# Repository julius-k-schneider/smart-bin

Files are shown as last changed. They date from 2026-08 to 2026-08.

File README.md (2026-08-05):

# AI-Powered Smart Waste Sorting Bin - Sortio

A prototype of a waste bin that sorts for you, plus the city dashboard that keeps an eye on a whole fleet of them.

- **The bin** (`pi/`, `printables/`) is a 3D printed housing with a Raspberry Pi. It detects someone stepping up, photographs what they are holding, has an AI classify it as Paper or Plastic and opens the matching flap with a servo. Ultrasonic sensors in the lids measure how full it is.
- **The dashboard** (`src/`, `scripts/`) is a React + Vite frontend on a FastAPI + SQLite backend. It shows fill levels of all bins across Cologne on a map, raises alerts and plans collection routes. Real bins report over a WebSocket; the remaining locations are simulated so the demo works without hardware.

## Repository layout

| Path | What it is | Documentation |
|---|---|---|
| `pi/` | Firmware for the bin - classification, flaps, fill-level reporting | [`pi/readme.md`](pi/readme.md) - wiring, GPIO pins, calibration, setup |
| `printables/` | STL files for the housing, gears and sensor mounts | [`printables/readme.md`](printables/readme.md) - part list and print settings |
| `scripts/` | Backend: REST API, WebSockets, SQLite, route generation | this file |
| `src/` | Dashboard frontend | this file |

## Compartment naming

The bin and the dashboard use different words for the same thing, because the dashboard models a standard three-compartment city bin while the prototype sorts two categories:

| Bin (`pi/smartbin.py`) | Dashboard / API | Meaning |
|---|---|---|
| Paper | `recycling` | Paper flap and the sensor in that lid |
| Plastic | `trash` | Plastic flap and the sensor in that lid |
| - | `compost` | Exists in the dashboard only, no hardware for it |

## Architecture

Three components that talk over two WebSockets and one REST API:

```mermaid
flowchart LR
    subgraph Bin["Smart bin (Raspberry Pi)"]
        S["HC-SR04 sensors<br/>trigger + 2× fill level"]
        C["Camera"]
        V["Servos / flaps"]
        P["pi/smartbin.py"]
        S --> P
        C --> P
        P --> V
    end

    AI["AI API<br/>(KIConnect NRW)"]
    P -- "photo (HTTPS)" --> AI
    AI -- "Paper / Plastic" --> P

    subgraph Server["Backend (scripts/)"]
        B["backend.py<br/>FastAPI"]
        D[("SQLite<br/>data/smart-bins.db")]
        R["route_service.py"]
        B <--> D
        B --> R
    end

    P -- "fill levels, 1 Hz<br/>ws://…/ws/ingest" --> B

    subgraph UI["Dashboard (src/)"]
        F["React + Vite"]
    end

    B -- "city snapshots<br/>ws://…/ws" --> F
    F -- "REST /api/*" --> B
```

The Pi does two independent jobs: classifying waste with the camera and the AI
API, and reporting how full its bins are. Only the second one talks to the
dashboard. Bins without hardware are simulated by the backend.

## Features

**Smart bin:**

- Proximity trigger with an ultrasonic sensor, then an automatic photo
- Waste classification through a vision AI model (KIConnect NRW), reduced to Paper, Plastic or "no waste detected"
- Servo-driven flap that only opens for the matching category
- OLED status display on the bin
- Two ultrasonic fill-level sensors, reported to the dashboard once per second
- Every peripheral is optional - a missing display, camera, servo or backend does not stop the rest

**Dashboard:**

- Responsive navigation with Overview, Smart Bins, Route Planning, Smart Analytics and Settings pages
- Persistent bin data and measurements in SQLite
- REST API for adding, deleting and inspecting bins
- Live city-wide WebSocket snapshot stream, pushed on every data change and at least every 30 seconds
- Device ingest WebSocket for real Raspberry Pi bins reporting their fill level once per second
- Cologne map using OpenStreetMap tiles through Leaflet
- 20 simulated smart bin locations around Cologne
- Threshold filter for collection planning
- Summary cards for total bins, full bins, almost-full bins, average fill, and connection status
- Sortable smart bin table and individual detail views
- Backend route generation with a nearest-neighbor heuristic
- Multi-part Google Maps export for generated collection routes
- Custom collection route start points
- Reusable map, address search and manual coordinate location picker
- Demo settings for pausing updates and resetting all fill levels
- Straight-line Haversine distance estimate for the MVP route
- Smart Analytics page with sustainability KPIs - note that this page shows hard-coded example figures, it is not calculated from the measurements

## Environment

Create `.env.local` in the project root when you want to override the default city WebSocket URL:

```env
VITE_SMART_BIN_CITY_URL=ws://localhost:8181/ws
VITE_SMART_BIN_API_URL=/api
```

If the file is missing, the frontend defaults to `ws://localhost:8181/ws` and `/api`.

## Run The Demo

Install frontend and backend dependencies:

```bash
npm install
pip install -r requirements.txt
```

Start the backend and simulator:

```bash
npm run server
```

The server provides REST endpoints and a WebSocket on port `8181`. Optional CLI arguments are:

```bash
npm run server -- 8181 cologne-smart-bin-mock
```

(`npm run mock-server` is an alias for the same command. It is the real backend either way - the "mock" only refers to the simulated bins it serves when no hardware is connected.)

Start the frontend in another terminal:

```bash
npm run dev
```

Open the Vite URL shown in the terminal, usually `http://localhost:5173`.

## Simulated Data

`scripts/backend.py` sends a city-wide frame whenever the data changes and, through the simulation loop, at least every 30 seconds. Every frame contains:

- `city: "Cologne"`
- `device_group_id`
- `timestamp_ms`
- `bins`

Note that a connected Raspberry Pi reports once per second, and every accepted device frame triggers a snapshot broadcast - so with real hardware attached the dashboard receives roughly one frame per second rather than one every 30 seconds.

The mock server simulates 20 stable locations around Cologne, including Koelner Dom, Koeln Hauptbahnhof, University of Cologne, Rheinauhafen, Neumarkt, Heumarkt, Stadtgarten, Deutz, Ehrenfeld, Nippes, Muelheim, Poller Wiesen, and Rheinpark.

Fill levels change only slightly during each update. Bin data, current fill levels and measurement history are stored in `data/smart-bins.db`.

## Real Hardware

### Bill of materials

Everything needed for one physical bin. The GPIO pins for each part are in [`pi/readme.md`](pi/readme.md).

| Qty | Part | Notes |
|---|---|---|
| 1 | Raspberry Pi with Raspberry Pi OS (Bookworm or newer) | needs `picamera2` / `rpicam-still` for the CSI camera path |
| 3 | HC-SR04 ultrasonic sensor | 1× trigger at the front, 2× fill level in the bin lids |
| 3 | Voltage divider, e.g. 1 kΩ + 2 kΩ resistor | **required** - the HC-SR04 ECHO pin outputs 5 V, the Pi GPIO is 3.3 V only |
| 1 | SG92R micro servo | Paper flap |
| 1 | SG90 micro servo | Plastic flap |
| 1 | SBC-OLED01 128×64 I2C display (address 0x3C) | optional - the program runs without it |
| 1 | Camera | either a CSI camera on the Pi, or a phone running the "IP Webcam" app (see `CAMERA_URL`) |
| 1 | 5 V power supply for the servos | driving both servos from the Pi's 5 V rail can brown it out |
| - | Jumper wires, screws | |
| - | 3D printed housing and mounts | STL files and print settings in [`printables/readme.md`](printables/readme.md) |

An account for the KIConnect NRW AI API is needed for the waste classification (`KICONNECT_API_KEY`, see [`pi/env.example`](pi/env.example)). Fill-level reporting works without it.

### Reporting protocol

A Raspberry Pi bin (`pi/smartbin.py`) reports its measured fill levels to the backend through a second WebSocket, `ws://<host>:8181/ws/ingest`. Each frame names the bin and one or more compartments:

```json
{
  "bin_id": "CGN-001",
  "timestamp_ms": 1737045000000,
  "compartments": {
    "recycling": { "fill_level_percent": 41.9, "distance_cm": 34.9 },
    "trash": { "fill_level_percent": 88.4, "distance_cm": 12.6 }
  }
}
```

The backend validates the frame, writes it to the database and broadcasts the updated city snapshot to every dashboard right away. Compartments that are not part of the frame keep their value. As long as a device is connected, its bin is excluded from the simulation, so real and simulated bins can run side by side. Device history is thinned to one entry per 30 seconds instead of one per frame.

The exclusion works per bin, not per compartment. The Pi has fill-level sensors for two compartments only (`recycling` and `trash`), so the `compost` value of a live bin keeps whatever it had before the device connected and no longer moves - the dashboard currently shows it like any other value. Keep that in mind when reading a live bin's compost level or its overall status.

Set `SMART_BIN_INGEST_TOKEN` on the backend to require the same token as a `?token=` query parameter on the ingest socket. If the variable is unset, the socket is open, which is fine for a local demo.

Wiring, GPIO pins, calibration and the Pi setup are documented in [`pi/readme.md`](pi/readme.md).

Address search uses the public OpenStreetMap Nominatim service only when a search is submitted. Search requests are limited to one per second and biased towards Cologne.

## Threshold And Routes

The dashboard defaults to an 80% collection threshold. Move the “Include bins from fill level” slider to include bins where at least one compartment is greater than or equal to the selected value.

Click “Generate collection route” to build a route from the fixed Waste Collection Depot. The current route optimizer:

- starts at the depot
- visits the nearest unvisited included bin
- continues until every included bin is visited
- returns to the depot
- estimates total distance with the Haversine formula

This is an MVP approximation with straight-line distances. It does not call a paid API and does not need API keys. The route service can later be replaced with OSRM, OpenRouteService, Google Maps, or another routing engine.

## Notes

- Python 3.10 or newer is required for the backend.
- The Raspberry Pi reports real fill levels; all other bins stay simulated.
- Dashboard user authentication is intentionally out of scope for this prototype.

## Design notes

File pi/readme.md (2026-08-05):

# Smart Bin - Raspberry Pi

`smartbin.py` runs on the bin itself. It does two independent jobs:

1. **Sorting** - when something comes close to the trigger sensor it takes a
   photo, has the AI classify it as Paper or Plastic and opens the matching
   flap with a servo.
2. **Fill-level reporting** - two more ultrasonic sensors sit in the lids and
   look down into the bins. Once per second their measurement is pushed to the
   dashboard backend over a WebSocket, where it replaces the simulated values.

Both run at the same time; the fill-level reporting lives in a background
thread and never blocks the sorting.

The dashboard those reports go to, the backend and the full bill of materials
are described in the [main README](../README.md). The printed parts are in
[`../printables/readme.md`](../printables/readme.md).

## Wiring

All sensors are HC-SR04 (5 V VCC, GND, TRIG, ECHO). **ECHO puts out 5 V and
must go through a voltage divider** (e.g. 1 kΩ / 2 kΩ) before it touches a Pi
GPIO, which is 3.3 V only.

| Function | Component | TRIG / Signal | ECHO |
|---|---|---|---|
| Trigger (object in front of the bin) | HC-SR04 | GPIO23 (Pin 16) | GPIO24 (Pin 18) |
| Fill level Paper -> section `recycling` | HC-SR04 | GPIO5 (Pin 29) | GPIO6 (Pin 31) |
| Fill level Plastic -> section `trash` | HC-SR04 | GPIO20 (Pin 38) | GPIO21 (Pin 40) |
| Flap Paper | SG92R servo | GPIO18 (Pin 12) | - |
| Flap Plastic | SG90 servo | GPIO17 (Pin 11) | - |
| Display | SBC-OLED01 (I2C, 0x3C) | SDA GPIO2 (Pin 3) | SCL GPIO3 (Pin 5) |

The pins are the `FILL_SENSORS` / `SERVO_PINS` constants at the top of
`smartbin.py`.

## Fill-level calibration

The distance from the sensor is converted into a percentage with two
constants in `smartbin.py`:

```python
BIN_EMPTY_CM = 55.0  # sensor -> bin floor, counts as 0 %
BIN_FULL_CM  = 7.0   # sensor -> waste surface when full, counts as 100 %
```

Measure both values once on the real bin and put them in. Each report is the
median of three pings, so a single bad echo does not show up in the dashboard.

## Setup

```bash
pip install -r requirements.txt

cp env.example ~/.kiconnect.env
chmod 600 ~/.kiconnect.env   # contains the API key
nano ~/.kiconnect.env        # fill in API key, camera and dashboard settings
```

The dashboard settings are:

| Variable | Meaning |
|---|---|
| `SMART_BIN_WS_URL` | Ingest socket of the backend, e.g. `ws://192.168.0.10:8181/ws/ingest` |
| `SMART_BIN_ID` | Which bin this Pi reports as - has to exist in the dashboard already |
| `SMART_BIN_INGEST_TOKEN` | Shared secret, must match the backend's `SMART_BIN_INGEST_TOKEN` |

Run it manually:

```bash
source ~/.kiconnect.env && python3 -u smartbin.py
```

Or as a service:

```bash
sudo cp smartbin.service /etc/systemd/system/
sudo systemctl enable --now smartbin
journalctl -u smartbin -f
```

## Behaviour when something is missing

Every peripheral is optional and the program keeps running without it: no OLED,
no camera, no servos, no `websocket-client`, no reachable dashboard. The
dashboard connection reconnects on its own with a backoff of 2 s up to 30 s, so
the Pi survives a backend restart without intervention.

This also covers failures at runtime, not just at startup: if a photo fails -
network camera unreachable, phone gone from the WLAN, CSI camera or
`rpicam-still` broken - the display shows `Camera error`, that trigger is
skipped and the program carries on. Fill-level reporting runs in its own thread
and is unaffected by camera or AI problems.

What each missing part costs you:

| Missing | Consequence |
|---|---|
| OLED | No display output, everything else works |
| Camera or AI key | No classification, no flap opens - fill levels still reported |
| Servos | Classification still runs and is shown, no flap moves |
| `websocket-client` or dashboard | No fill levels in the dashboard, sorting works |
| Fill-level sensor without echo | That compartment is skipped in the report, the other one is still sent |

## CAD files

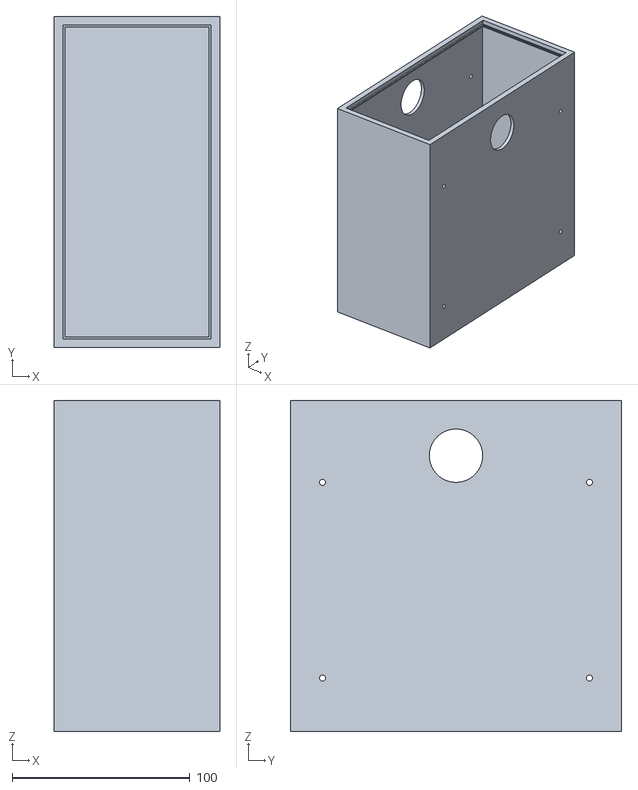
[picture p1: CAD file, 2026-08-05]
printables/middle.stl
93.0 x 186.0 x 186.0

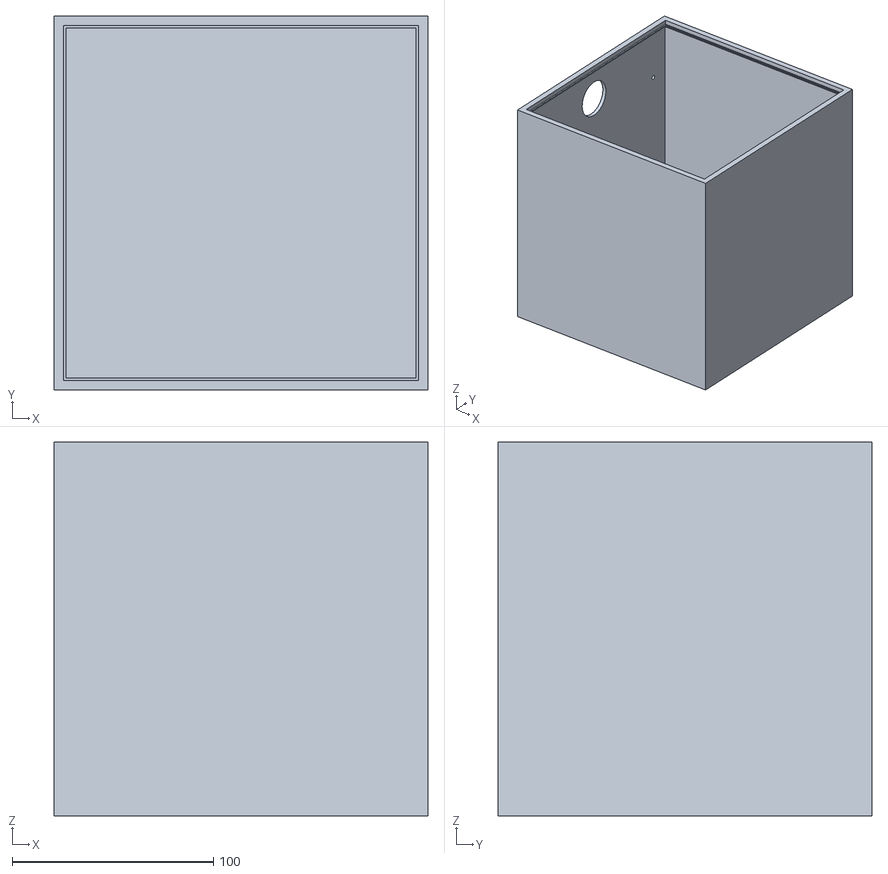
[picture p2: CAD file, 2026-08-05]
printables/bin.stl
186.0 x 186.0 x 186.0

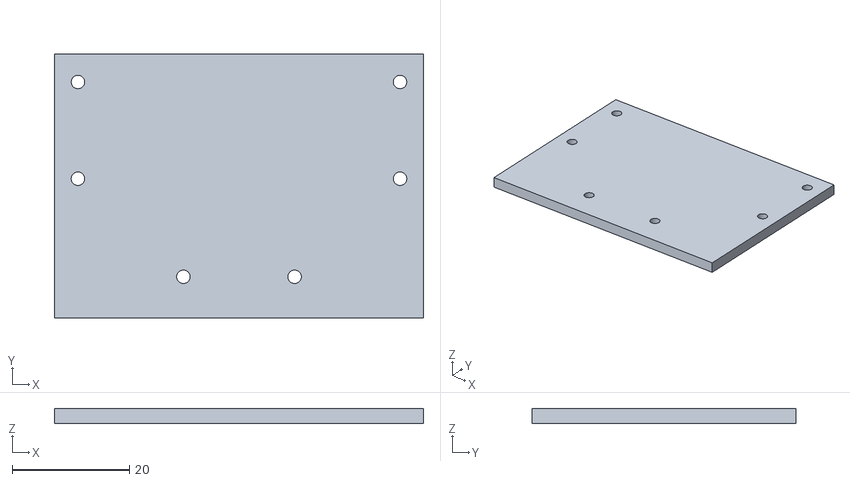
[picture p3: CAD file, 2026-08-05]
printables/holding_plate.stl
63.0 x 45.0 x 2.50

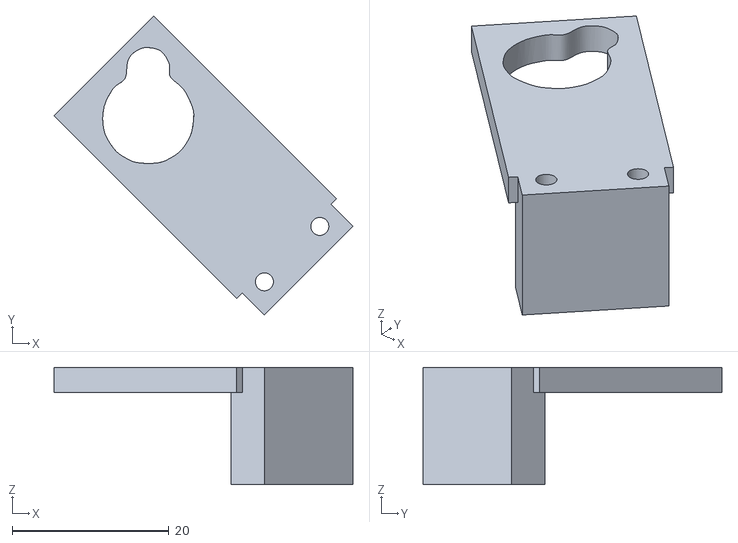
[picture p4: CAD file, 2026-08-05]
printables/servo_holder.stl
38.2 x 38.2 x 15.0

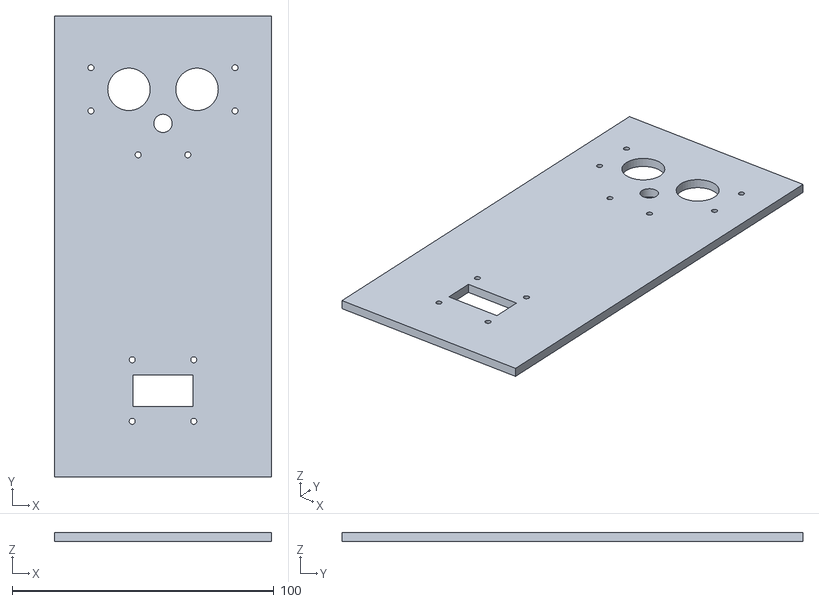
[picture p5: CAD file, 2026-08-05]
printables/lid_middle.stl
83.0 x 176.0 x 3.50

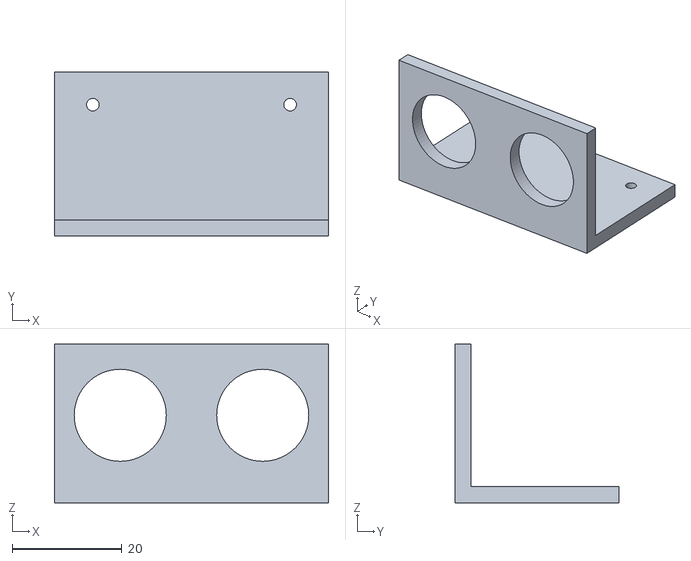
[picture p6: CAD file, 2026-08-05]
printables/distance_sensor_holder.stl
50.0 x 30.0 x 29.0

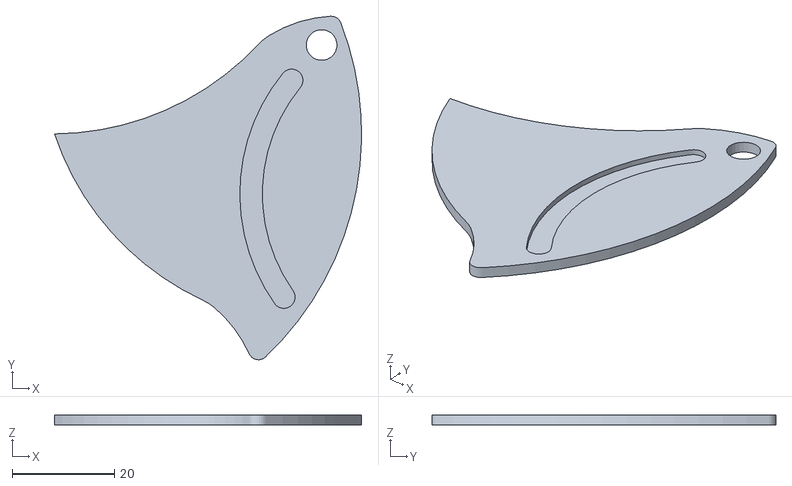
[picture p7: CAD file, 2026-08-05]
printables/door_blade.stl
60.0 x 67.1 x 2.00

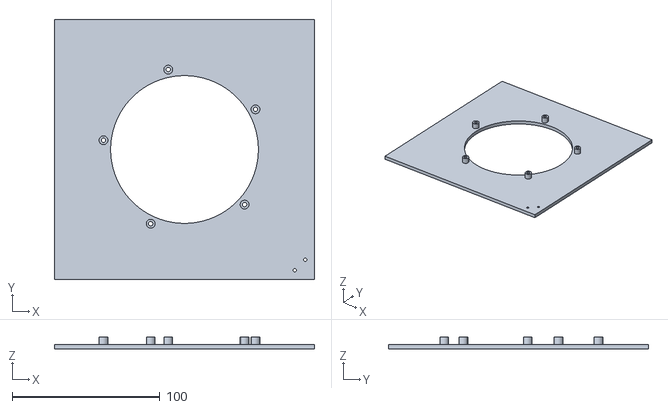
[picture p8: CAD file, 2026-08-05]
printables/lid_bin.stl
176.0 x 176.0 x 8.20

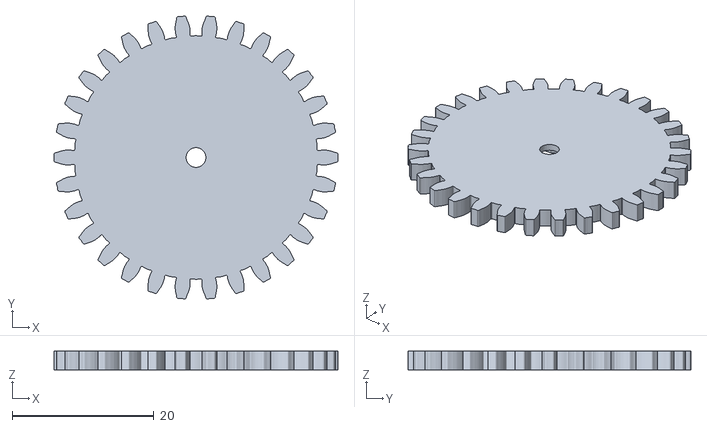
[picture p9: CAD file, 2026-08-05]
printables/pinion.stl
40.1 x 39.9 x 2.64

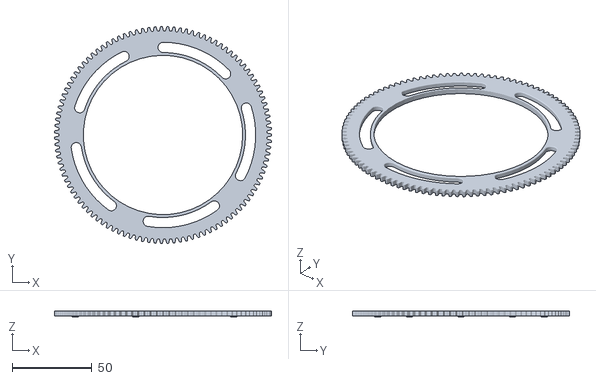
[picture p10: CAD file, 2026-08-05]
printables/ring_gear.stl
136.2 x 136.2 x 3.80

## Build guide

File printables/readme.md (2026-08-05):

# Smart Bin - 3D printed parts

All STL files for the bin housing, the sorting mechanism and the sensor/servo
mounts. Dimensions below are the actual bounding boxes of the STL files, so you
can check them against your printer before slicing.

## Part list

| File | Size (X × Y × Z, mm) | Qty | What it is |
|---|---|---|---|
| `bin.stl` | 186 × 186 × 186 | 2 | The waste container itself - one per category (Paper, Plastic) |
| `middle.stl` | 93 × 186 × 186 | 1 | Middle section between the two bins |
| `lid_bin.stl` | 176 × 176 × 8.2 | 2 | Lid for `bin.stl`, holds the fill-level sensor looking down |
| `lid_middle.stl` | 83 × 176 × 3.5 | 1 | Lid for the middle section |
| `door_blade.stl` | 60 × 67.1 × 2 | 2 | Flap that opens the way into one bin, driven by a servo |
| `ring_gear.stl` | 136.2 × 136.2 × 3.8 | 1 | Ring gear of the flap drive |
| `pinion.stl` | 40.1 × 39.9 × 2.6 | 1 | Pinion on the servo horn, drives the ring gear |
| `servo_holder.stl` | 38.2 × 38.2 × 15 | 2 | Mount for the SG90 / SG92R servos |
| `distance_sensor_holder.stl` | 50 × 30 × 29 | 3 | Mount for an HC-SR04 |
| `holding_plate.stl` | 63 × 45 × 2.5 | 1 | Mounting plate for the electronics |

The quantities follow the wiring in [`../pi/readme.md`](../pi/readme.md): two
servos and two flaps (one per category), three HC-SR04 (one trigger sensor at
the front, one in each bin lid). Print a single bin and one lid if you only
want to test one category.

## Build volume

`bin.stl` and `middle.stl` are **186 mm tall**, so you need a printer with at
least ~190 mm in Z (an Ender 3 or Prusa MK-series is fine, a Prusa Mini at
180 mm is not). Everything else fits on any common bed.

## Suggested print settings

These are starting values, not measured project settings - adjust them to your
printer and filament.

| | Structural parts (`bin`, `middle`, lids, `holding_plate`) | Gears (`ring_gear`, `pinion`) | Mounts (`servo_holder`, `distance_sensor_holder`, `door_blade`) |
|---|---|---|---|
| Material | PLA or PETG | PETG (less wear) | PLA or PETG |
| Layer height | 0.2 mm | 0.15 mm | 0.2 mm |
| Infill | 15 % | 30-40 % | 25 % |
| Perimeters | 3 | 4 | 3 |
| Supports | only for overhangs in the lids | no | no |

Notes:

- Print the gears with a **finer layer height** - tooth flanks that are too
  coarse make the flap drive jam.
- `door_blade.stl` is only 2 mm thick and slides. Print it flat, and if it is
  tight in the ring gear, sand the edge instead of scaling the part.
- If the servo does not sit tight in `servo_holder.stl`, your printer is likely
  printing slightly small - check the horizontal expansion / XY compensation
  setting rather than editing the STL.

Wiring, GPIO pins and calibration are documented in
[`../pi/readme.md`](../pi/readme.md), the electronics you need to buy are listed
in the [main README](../README.md).

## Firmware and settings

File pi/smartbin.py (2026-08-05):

#!/usr/bin/env python3
"""Smart-Bin: on proximity (< THRESHOLD_CM) takes a photo, sends it to the AI
API (KIConnect NRW) for waste classification and shows the result on the OLED.
It then opens the matching bin flap (Paper / Plastic) with a servo.

Two more distance sensors sit inside the bins and measure how full they are;
that value is pushed to the dashboard backend over a WebSocket every second.

- Trigger sensor: HC-SR04 on GPIO23 (TRIG) / GPIO24 (ECHO, via resistor).
  Raw measurement with RPi.GPIO + internal pull-down (robust, with timeouts).
- Fill-level sensors: one HC-SR04 per bin, mounted in the lid looking down.
  Paper on GPIO5/GPIO6, Plastic on GPIO20/GPIO21 (see FILL_SENSORS).
- Camera: network camera (phone app "IP Webcam") via CAMERA_URL; falls back to
  the local CSI camera (picamera2) or rpicam-still if CAMERA_URL is unset.
- Display: SBC-OLED01 128x64 on I2C-1 (SDA Pin3 / SCL Pin5), address 0x3C.
- AI: photo -> OpenAI-compatible /chat/completions -> category + reason.
  Credentials come from environment variables (see env.example):
    KICONNECT_BASE_URL, KICONNECT_API_KEY, KICONNECT_MODEL, CAMERA_URL
- Dashboard: SMART_BIN_WS_URL, SMART_BIN_ID, SMART_BIN_INGEST_TOKEN.
- Images are stored with a timestamp in ~/captures/.
"""
import base64
import json
import os
import re
import subprocess
import threading
import urllib.request
import urllib.error
from datetime import datetime
from pathlib import Path
from time import sleep, time

import RPi.GPIO as GPIO

# --- Configuration ---
TRIG = 23
ECHO = 24
# Fill-level sensors: one HC-SR04 per bin, mounted in the lid looking straight
# down at the waste. Keyed by the dashboard section they report to.
# GPIO5/6 and GPIO20/21 are free here - the trigger sensor uses 23/24, the
# servos 17/18 (hardware PWM pins stay clear) and the OLED sits on I2C (2/3).
FILL_SENSORS = {
    "recycling": {"flap": "Paper", "trig": 5, "echo": 6},
    "trash": {"flap": "Plastic", "trig": 20, "echo": 21},
}
BIN_EMPTY_CM = 55.0    # sensor -> bin floor, counts as 0 % full
BIN_FULL_CM = 7.0      # sensor -> waste surface, counts as 100 % full
FILL_SAMPLES = 3       # median over N pings - kills ultrasonic outliers
FILL_PING_GAP_S = 0.06 # HC-SR04 needs a short pause between pings
REPORT_INTERVAL_S = 1.0  # how often the fill levels go to the dashboard

# Dashboard backend (scripts/backend.py). SMART_BIN_ID must match a bin that
# already exists in the dashboard, otherwise the backend rejects the frames.
DASHBOARD_URL = os.environ.get("SMART_BIN_WS_URL", "ws://192.168.0.10:8181/ws/ingest")
BIN_ID = os.environ.get("SMART_BIN_ID", "CGN-001")
INGEST_TOKEN = os.environ.get("SMART_BIN_INGEST_TOKEN", "")
RECONNECT_MAX_S = 30.0
THRESHOLD_CM = 15.0    # trigger when distance is below this
PRE_PHOTO_S = 0.5      # wait after trigger before the photo (avoids motion blur)
NUM_PHOTOS = 1         # number of photos per trigger
COOLDOWN_S = 3.0       # lock-out after a trigger
MEAS_TIMEOUT_S = 0.03  # max wait per echo edge
RESULT_S = 5.0         # how long the result stays on the display
SAVE_DIR = Path.home() / "captures"

# Camera: picamera2 keeps the camera open (fast, <1 s/photo). Keep resolution
# moderate - enough for classification and small to upload. rpicam-still stays
# a fallback if picamera2 is missing.
CAMERA_SIZE = (1280, 960)
CAMERA_WARMUP_S = 1.5  # once at startup, for exposure/white balance

# Network camera (e.g. phone app "IP Webcam"): if CAMERA_URL is set, the photo
# is fetched via HTTP from there instead of the CSI camera.
# Example: CAMERA_URL="http://192.168.178.99:8080/shot.jpg"
CAMERA_URL = os.environ.get("CAMERA_URL", "")

# Servos (SG92R + SG90): one servo per bin/category.
# Motion: CLOSED (0 deg) -> OPEN (180 deg), hold SERVO_OPEN_S, then CLOSED again.
SERVO_PINS = {"Paper": 18, "Plastic": 17}
SERVO_FREQ = 50        # Hz - standard for hobby servos (20 ms period)
SERVO_CLOSED = 0.0     # closed end position (deg) - one edge
SERVO_OPEN = 180.0     # open end position (deg) - the opposite edge
SERVO_MOVE_S = 0.6     # time for the servo to reach the end position
SERVO_OPEN_S = 5.0     # how long the flap stays open

# AI API (from environment; defaults as fallback)
AI_URL = os.environ.get("KICONNECT_BASE_URL", "https://chat.kiconnect.nrw/api/v1")
AI_KEY = os.environ.get("KICONNECT_API_KEY", "")
AI_MODEL = os.environ.get("KICONNECT_MODEL") or "Mistral Small 3-2-24b Instruct KI:Inferenz.nrw"

CATEGORIES = ("Paper", "Plastic")  # only these open a bin
SYSTEM_PROMPT = (
    "You are a waste classifier for a smart bin. "
    "You get a photo. If it clearly shows a single waste item, classify it as "
    "EXACTLY one of: Paper, Plastic. "
    "If NO waste is visible - for example only a hand, an empty scene, or an "
    "unrelated object - use the category None. "
    "Reply ONLY with a JSON object in exactly this format, no other text, no Markdown: "
    '{"category": "<Paper|Plastic|None>", "reason": "<max 8 words, in English>"}. '
    "Choose exactly one category. Do not express uncertainty."
)

SAVE_DIR.mkdir(exist_ok=True)

# --- GPIO setup (internal pull-down keeps ECHO cleanly LOW at rest) ---
GPIO.setmode(GPIO.BCM)
GPIO.setwarnings(False)
GPIO.setup(TRIG, GPIO.OUT)
GPIO.setup(ECHO, GPIO.IN, pull_up_down=GPIO.PUD_DOWN)
GPIO.output(TRIG, False)
for _sensor in FILL_SENSORS.values():
    GPIO.setup(_sensor["trig"], GPIO.OUT)
    GPIO.setup(_sensor["echo"], GPIO.IN, pull_up_down=GPIO.PUD_DOWN)
    GPIO.output(_sensor["trig"], False)
sleep(0.3)

# The three HC-SR04 run from two threads - without this lock they would ping
# into each other's echo window and report garbage.
_ping_lock = threading.Lock()
_stop = threading.Event()

# --- WebSocket client for the dashboard (optional, fails cleanly) ---
try:
    import websocket  # pip install websocket-client
except ImportError as e:
    websocket = None
    print(f"websocket-client missing ({e}) - no fill levels sent to the dashboard.")

# --- Servos (optional, fail cleanly) ---
_servos = {}  # category -> GPIO.PWM
try:
    _closed_duty = 2.5 + (SERVO_CLOSED / 180.0) * 10.0  # duty for the closed position
    for _cat, _pin in SERVO_PINS.items():
        GPIO.setup(_pin, GPIO.OUT)
        _pwm = GPIO.PWM(_pin, SERVO_FREQ)
        _pwm.start(_closed_duty)  # move to closed position at startup
        _servos[_cat] = _pwm
    sleep(SERVO_MOVE_S)       # time for both to reach the closed position
    for _pwm in _servos.values():
        _pwm.ChangeDutyCycle(0)  # pulse off -> servo quiet/power saving
    print(f"Servos ready: {[(k, SERVO_PINS[k]) for k in _servos]}")
except Exception as e:
    _servos = {}
    print(f"Servos unavailable ({e!r}) - continuing without servos.")
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

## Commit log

2026-08-05 Add 3D models
    [bin.stl, distance_sensor_holder.stl, door_blade.stl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]
2026-08-05 Report real fill levels from the Pi to the dashboard
    Add two HC-SR04 fill-level sensors to the bin and stream their readings to
    the dashboard backend over a WebSocket once per second.
    Pi (pi/smartbin.py):
    - Paper sensor on GPIO5/6, Plastic on GPIO20/21; 23/24, 17/18 and I2C stay free
    - Distance to percent via BIN_EMPTY_CM/BIN_FULL_CM, median of three pings
    - Background thread keeps the socket open and reconnects with 2s..30s backoff
    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
2026-08-05 Keep the bin running when the camera fails
    A failing photo took the whole program down: photo() had no error handling
    and the main loop only catches KeyboardInterrupt. An unreachable network
    camera (URLError), a broken CSI camera (RuntimeError) or a missing
    rpicam-still (CalledProcessError) therefore also killed the fill-level
    reporting, which has nothing to do with the camera.
    capture_and_classify() now catches the failure, shows "Camera error" on the
    OLED and skips that trigger. The background reporting thread is unaffected.
    This is what pi/readme.md already promised ("no camera ... keeps running"),
    so the section now spells out that runtime failures are covered too and adds
    a table of w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
    [smartbin.py]
2026-08-05 Document the hardware, the parts to print and the real broadcast rate
    printables/readme.md was empty. It now lists every STL with its actual
    bounding box (parsed from the files), the quantity needed per bin, a build
    volume warning - bin.stl and middle.stl are 186 mm tall - and suggested
    print settings.
    README.md gains an architecture diagram and a bill of materials, including
    the voltage divider the HC-SR04 ECHO lines need.
    Two corrections to existing text:
    - The city snapshot is not sent "every 30 seconds". Every accepted device
    frame triggers a broadcast, so a connected Pi produces about one per
    second.
    - Excluding a live bin from the simulation works per bin, not per
    compartment.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
2026-08-05 Describe the whole system in the README, not just the dashboard
    The repository grew a Raspberry Pi bin and 3D printed parts, but the README
    still introduced the project as a dashboard. It now leads with both halves
    and adds a repository layout table pointing at the two sub-READMEs, which in
    turn link back.
    Fixes along the way:
    - The project had two names: the README title said "Smart Waste Management
    Dashboard", index.html says "AI-Powered Smart Waste Sorting Bin". Now both
    agree.
    - Sorting, classification and the flaps were missing from the feature list
    entirely.
    - Only four of the five dashboard pages were listed - Smart Analytics was
    missing, and its figures are hard-coded, which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
